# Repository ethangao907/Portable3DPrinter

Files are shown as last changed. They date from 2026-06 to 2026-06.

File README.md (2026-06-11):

# Portable 3D Printer
**I document everything here** https://www.instagram.com/gao.lab/

**Latest Reel** https://www.instagram.com/p/DYTzN6iu2yM/

**Engineering plastics capable, enclosed, direct drive, folding portable 3D printer that fits in a bag**

This printer collapses to a thin slab roughly the size of a laptop bag, then expands on a scissor-lift Z axis into a useful print volume. It is built almost entirely from 3D-printed parts on consumer machines, takes power from the same M18/DeWalt-class packs, and runs an enclosed heated chamber for ABS, ASA, and nylon. 
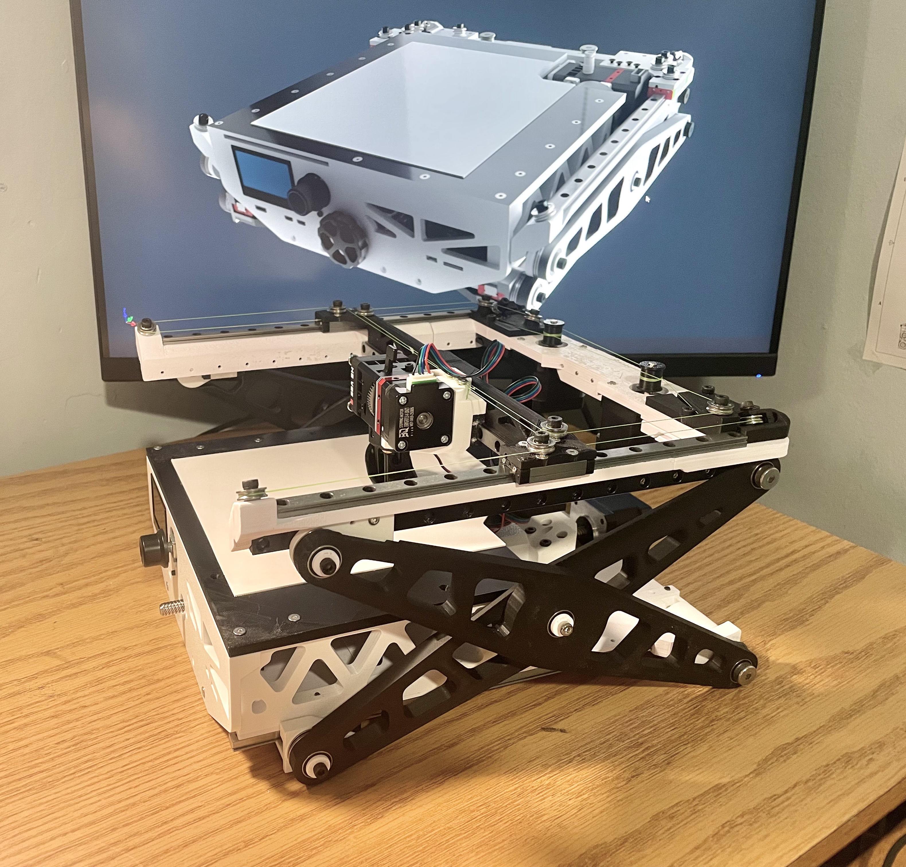
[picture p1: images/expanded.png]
Printer deployed


> **Status:** the v1 prototype is built and prints. v2, the version this repo is moving toward, is in active development. 

Desktop printers waste their whole volume when idle: the frame has to stay as tall as the full Z travel even when nothing is printing. This design stores that Z travel mechanically with a scissor lift, so the machine folds down to about **300 × 300 × 80 mm** and opens up to a **~180 × 200 × 175 mm** build volume. Nothing on the market targets *actual* portability, most "compact" printers are still stationary.

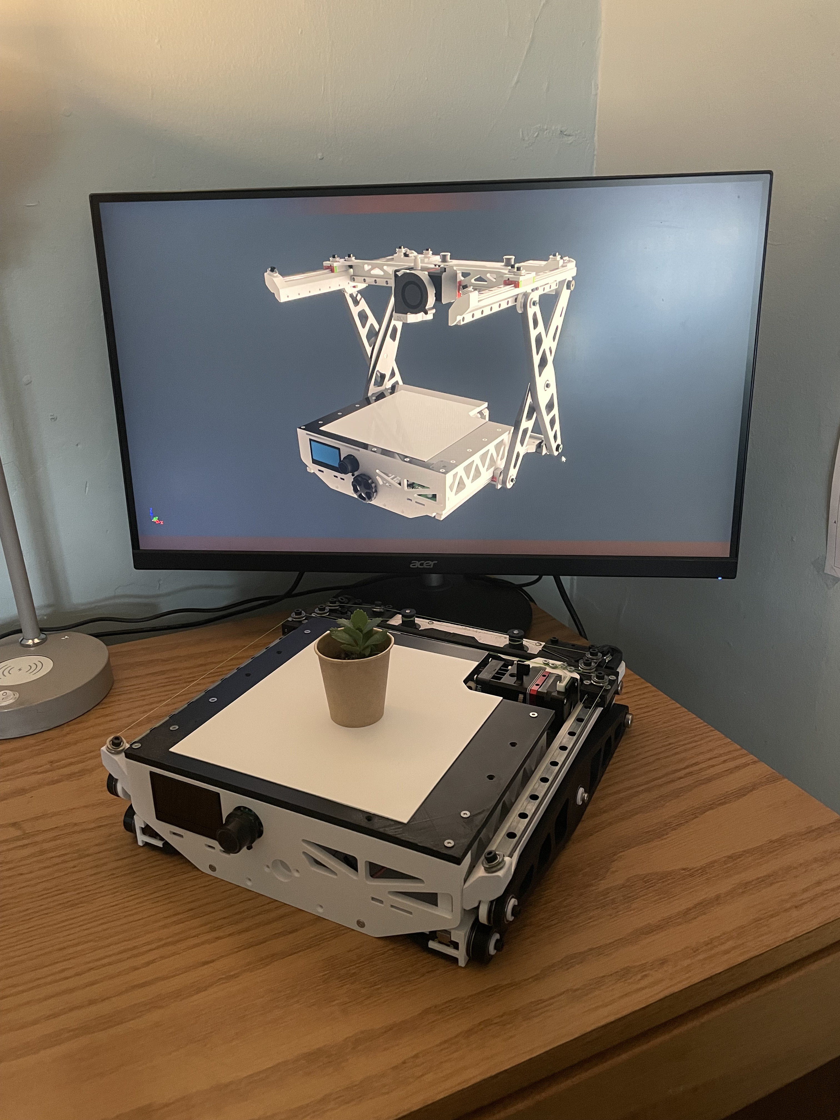
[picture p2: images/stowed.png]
Printer folded flat


The trade-off is that scissor lifts amplify backlash and load at low angles, so pivot quality, preload, bearing choice, and arm stiffness all matter. The build uses two preloaded pivots per side, thrust/axial bearings clamped with bolts, ~50 × 6 mm shoulder bolts at the stationary bottom pivot pair, and compliant printed clamps to hold everything tight.

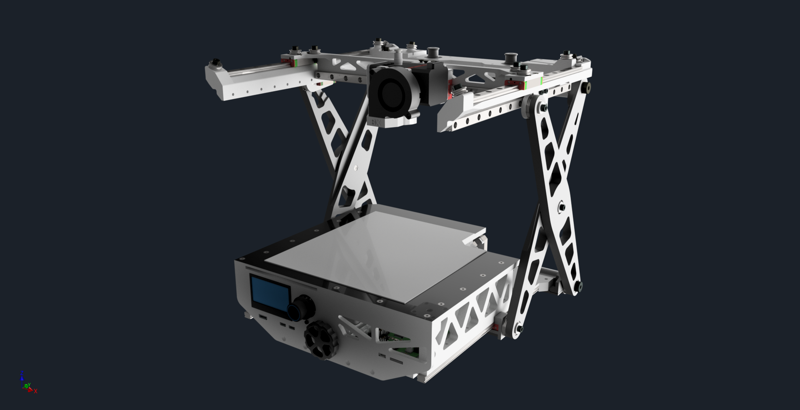
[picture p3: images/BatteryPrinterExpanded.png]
CAD Expanded

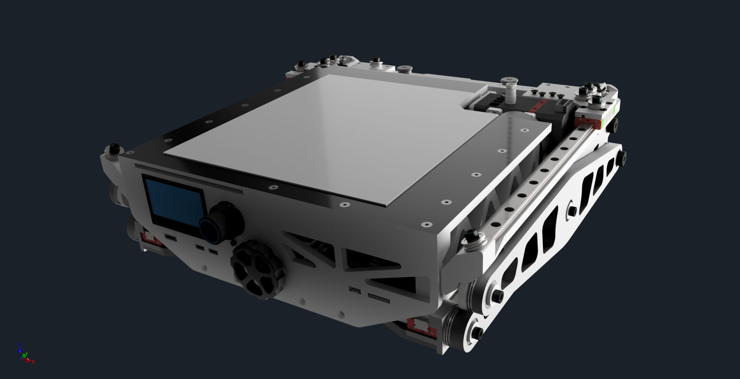
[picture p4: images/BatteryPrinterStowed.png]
CAD Stowed


## Inside the machine

The control stack runs a BTT SKR Mini E3 V3 with a Raspberry Pi 4 for higher-level control, on a 24 V bus, under Klipper. Klipper matters here specifically because a scissor lift has a **nonlinear** relationship between motor motion and nozzle height — software compensation maps motor position to true Z, which a conventional vertical gantry never needs.

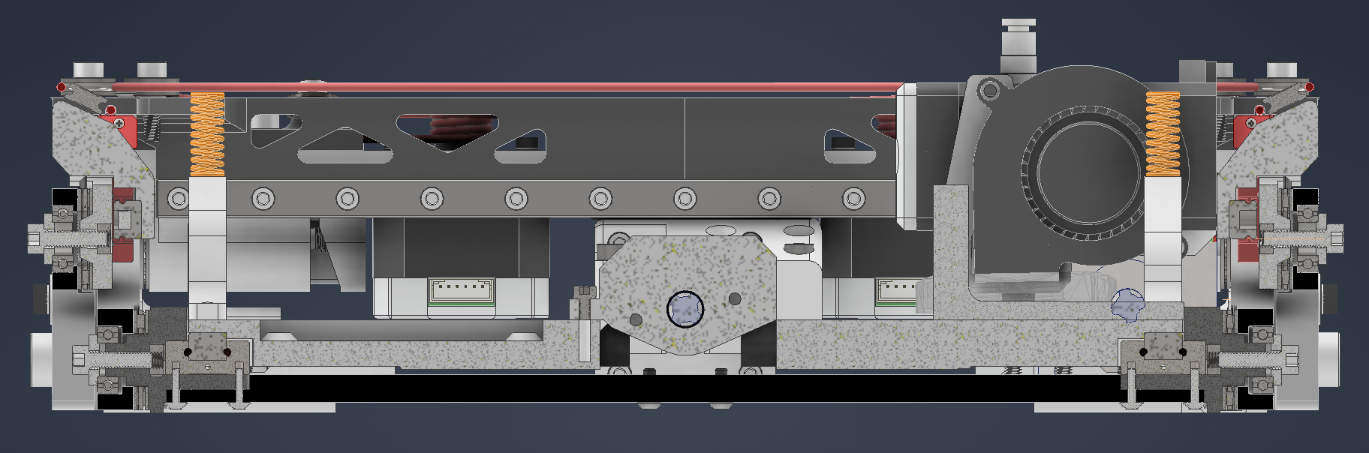
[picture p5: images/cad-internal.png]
Internal CAD


---

## Roadmap

v2 is a significant rework. The single central lead screw in v1 dictated the entire superstructure — the bottom bridge plate had to tie the two sides together, which forced the surrounding frames. **Removing the central screw in favor of two independent side lead screws collapses that dependency chain and opens a large central cavity** big enough to carry a full 1 kg spool inside the machine. Shortening the rear pivot bolts opens further space.

The other v2 changes follow from a deliberate repositioning. v1 was built around "battery + low power, *therefore* no heated bed." v2 drops the onboard battery entirely (it's a liability, and true off-grid printing is rare in practice), adds a **heated bed** and a **folding bellows enclosure** for a warm chamber, and takes power from a **power-tool battery** mounted on the front.

Remaining v2 work:

- Dual side lead screws with software Z-tilt leveling
- Folding bellows enclosure targeting a 50–60 °C chamber
- Heated bed sized for the chamber and power budget
- Power-tool battery mounting blocks (front), replacing the screen
- Custom 90° hotend with rear cable routing (kills the floppy top conduit)
- 3 mm GT2 belt drive — HBot first, falling back to CoreXY if racking forces are too high

## Bill of materials

*Coming soon.* Core components: MGN9 linear rails (×3), NEMA 17 motors, T8 lead screws, U-groove pulleys / GT2 belt, thrust + deep-groove bearings, shoulder bolts for pivots, BTT SKR Mini E3 V3, Raspberry Pi 4.

## Build instructions

*Coming soon.* The structure is designed to print on Ender 3–class machines with no machined parts. CAD and design files are in the [`Scissor 3D Printer`](Scissor%203D%20Printer) folder.

## Firmware

Klipper, with nonlinear Z mapping for the scissor geometry. Configuration and flashing notes will live in a `/firmware` folder.

## License

- **Firmware and software:** [GNU GPLv3](LICENSE) — modify and redistribute freely; derivatives must stay open and credit the original.
- **Hardware design files** (CAD, STEP, drawings): [CERN-OHL-S v2](LICENSE-hardware) — same share-alike philosophy, written for hardware.

- Build videos and project updates: [gao.lab](https://www.instagram.com/@gao.lab)

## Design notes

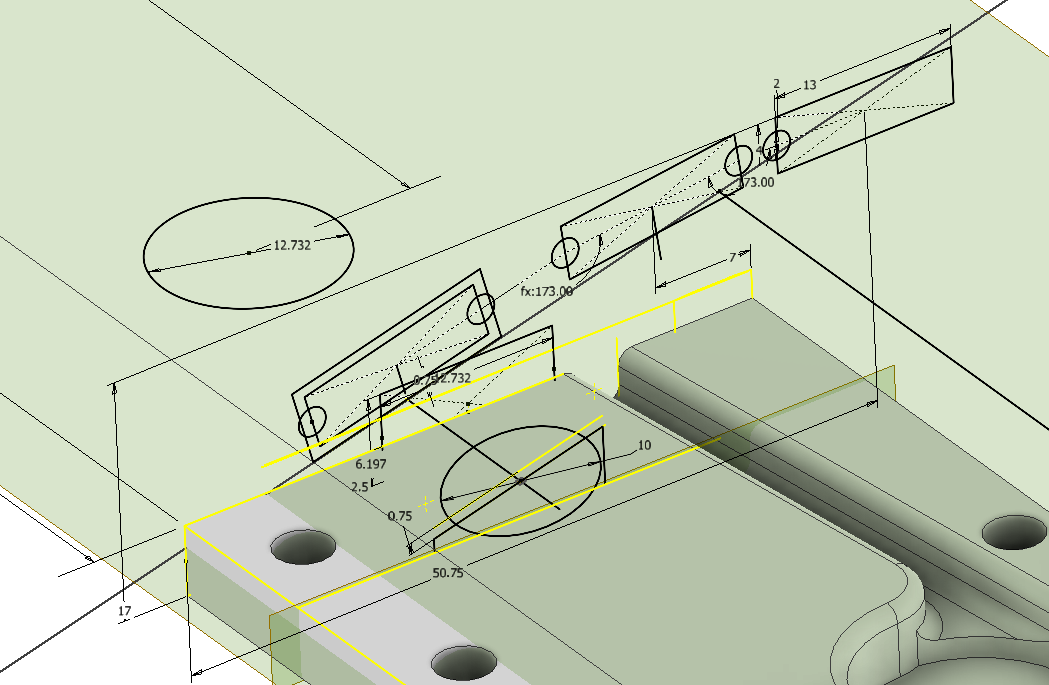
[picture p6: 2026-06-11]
images/Screenshot 2026-04-01 205350.png

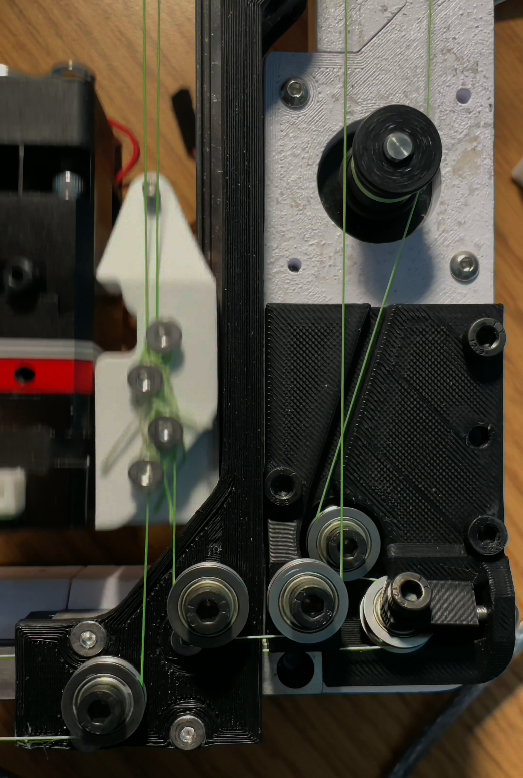
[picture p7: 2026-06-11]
images/Screenshot 2026-04-26 201614.png

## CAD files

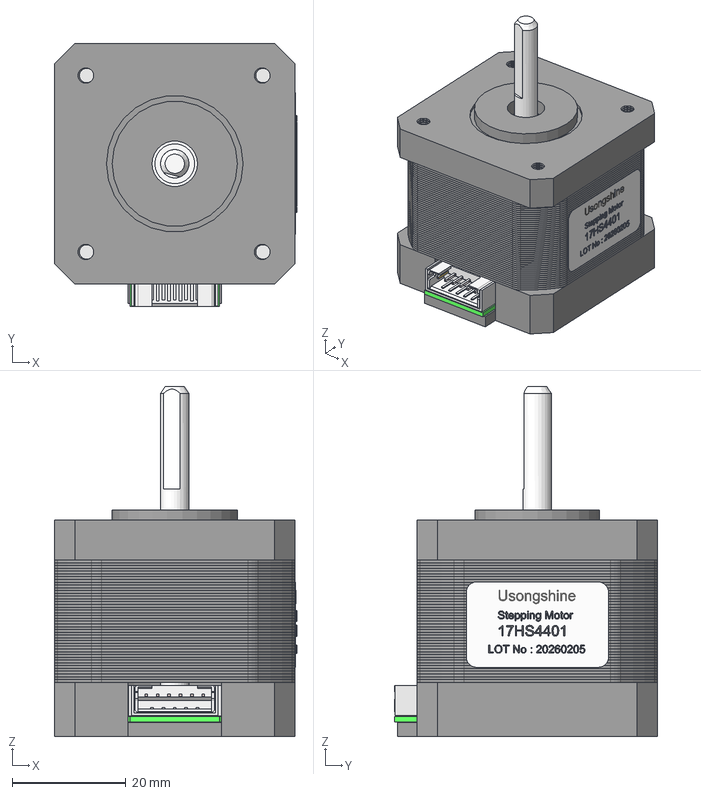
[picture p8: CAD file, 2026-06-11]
Scissor 3D Printer/nema17_17HS4401_b.step
42.5 x 46.2 x 61.5 mm
Bottom
Sheet_metal
Top_body
Axis
625ZZ_001 x 2
Sticker
C-440054-6
PCB
Conn_cover
M3x16-Vis x 4

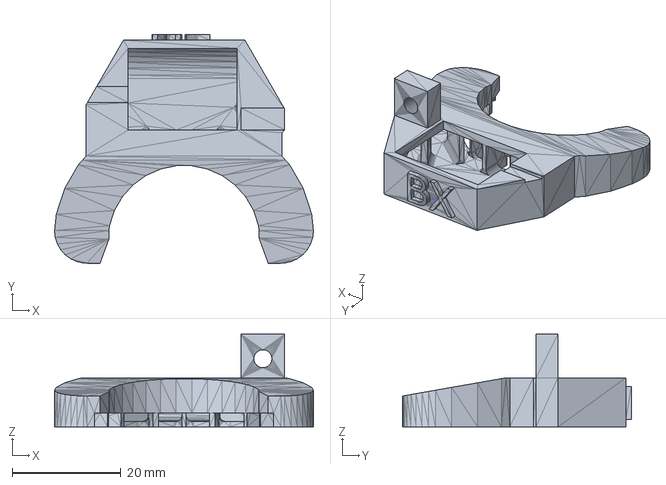
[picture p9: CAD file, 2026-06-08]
V2/ImageToStl.com_Fan_Duct/Fan_Duct.step
47.6 x 42.0 x 17.0 mm

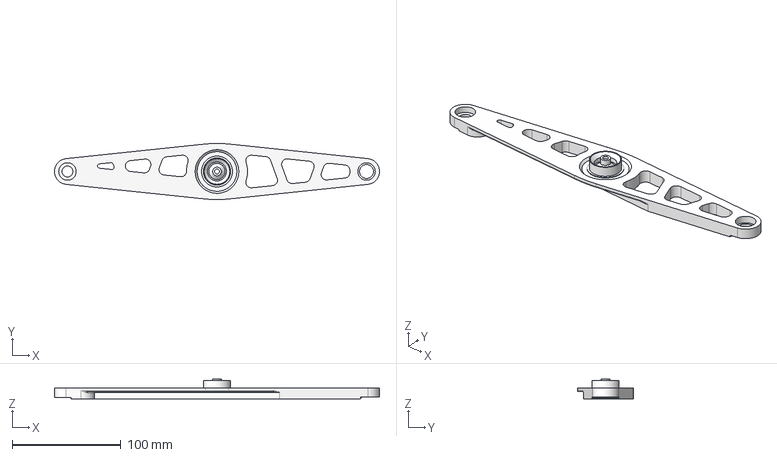
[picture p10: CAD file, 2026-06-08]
V2/Production/ScissorArmV2Inner.stp
298.8 x 51.6 x 18.0 mm

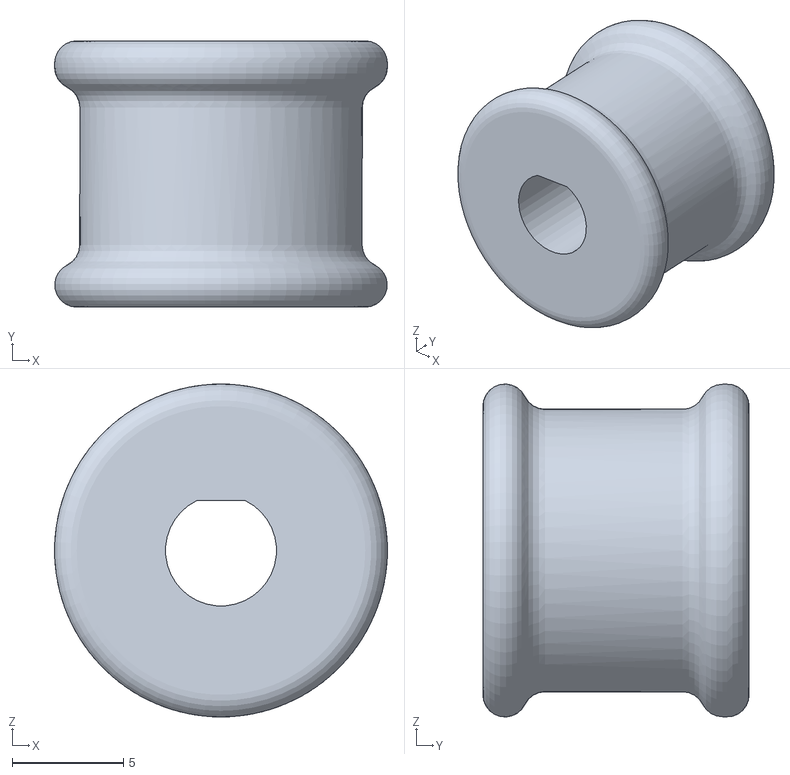
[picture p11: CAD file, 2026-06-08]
V2/STLs/Pulley.stl
15.0 x 12.0 x 15.0

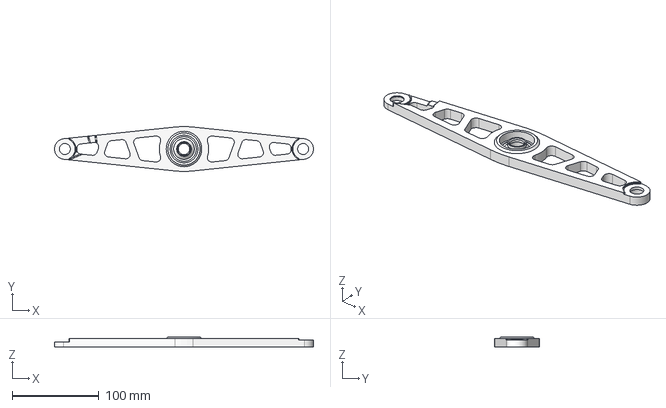
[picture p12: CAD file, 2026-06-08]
V2/Production/ScissorArmV2_MIR.stp
298.8 x 51.6 x 12.0 mm

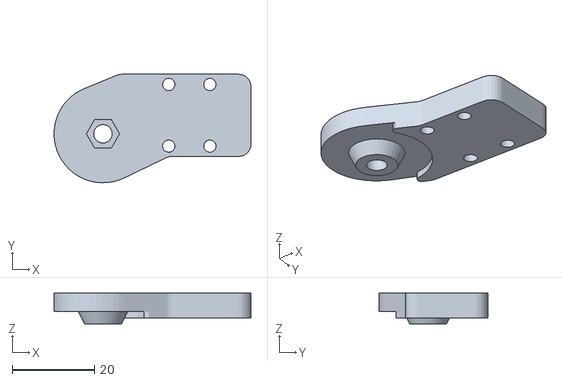
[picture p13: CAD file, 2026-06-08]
V2/STLs/UpperCarriagePivotMount_MIRV2.stl
47.9 x 26.4 x 7.50

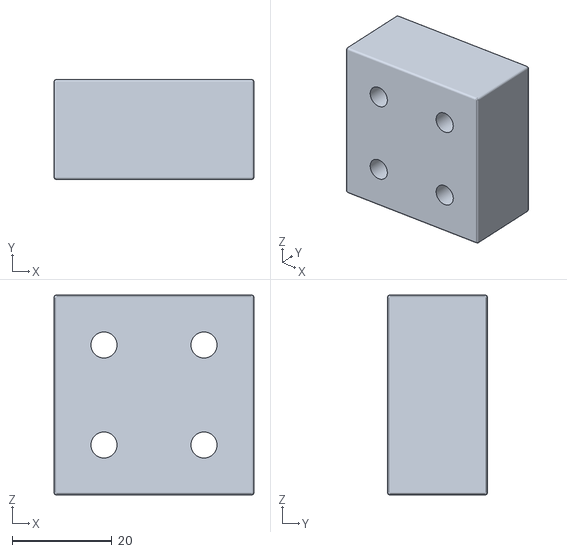
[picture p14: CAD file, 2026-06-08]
V2/4040_Spacer.stl
40.0 x 20.0 x 40.0

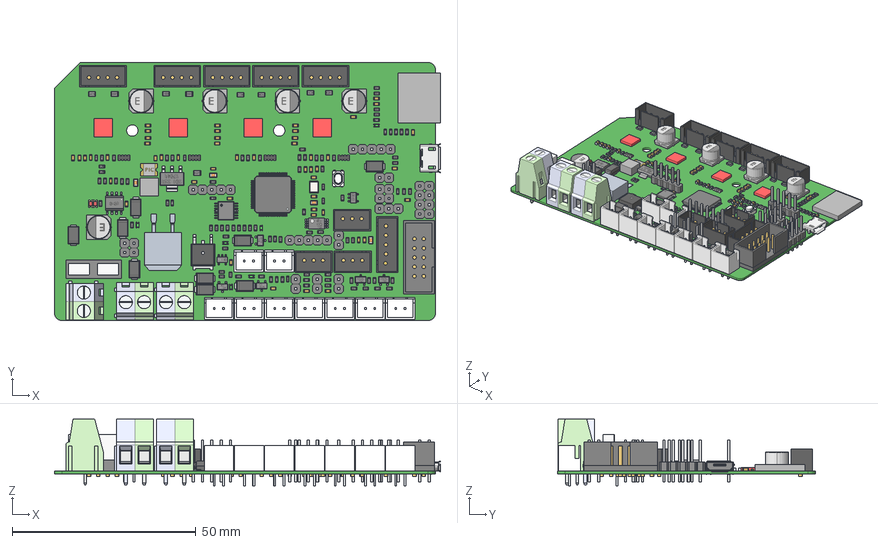
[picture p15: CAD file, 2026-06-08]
V2/BTT E3 SKR MINI V3.0.step
105.1 x 70.2 x 18.1 mm
Strip
Button
Sheet_Metal_Part6 x 2
Pin
DO214AC-SMA_S1G x 9
R0603 x 90
User_Library-XH2_54_2PIN x 9
User_Library-LED_0603_G_Pocket002 x 6
User_Library-LED_0603_G_Pad004 x 6
User_Library-LED_0603_G_Fillet x 6
User_Library-LED_0603_G_Pocket001 x 6
User_Library-LED_0603_G_Pad x 6
KF128 x 3
Extruded x 204
LOGO?
USB_micro_A
User_Library-led_0805 x 2
TQFP-64_10x10
TSSOP-8
SO-8
User_Library-0805_SMD_Capacitor x 4
SL-E x 5
R0805 x 9
TO-252
User_Library-R-0603-Array-4-1 x 4
SOT-223_MP04A
User_Library-GeyerElectronics_KX7
TO263
TSSOP14-1
SOT-23-5 x 2
User_Library-R1812-PTC

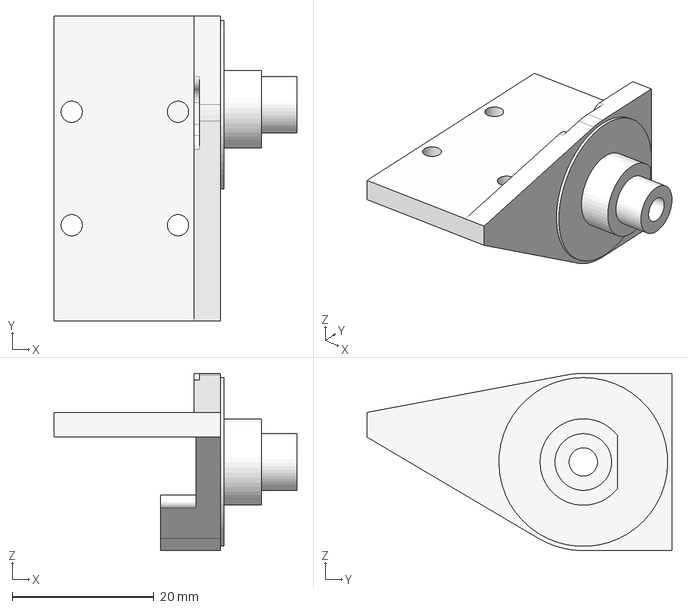
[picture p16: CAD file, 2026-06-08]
V2/Production/CarriagePivotMount.stp
34.3 x 43.0 x 25.0 mm

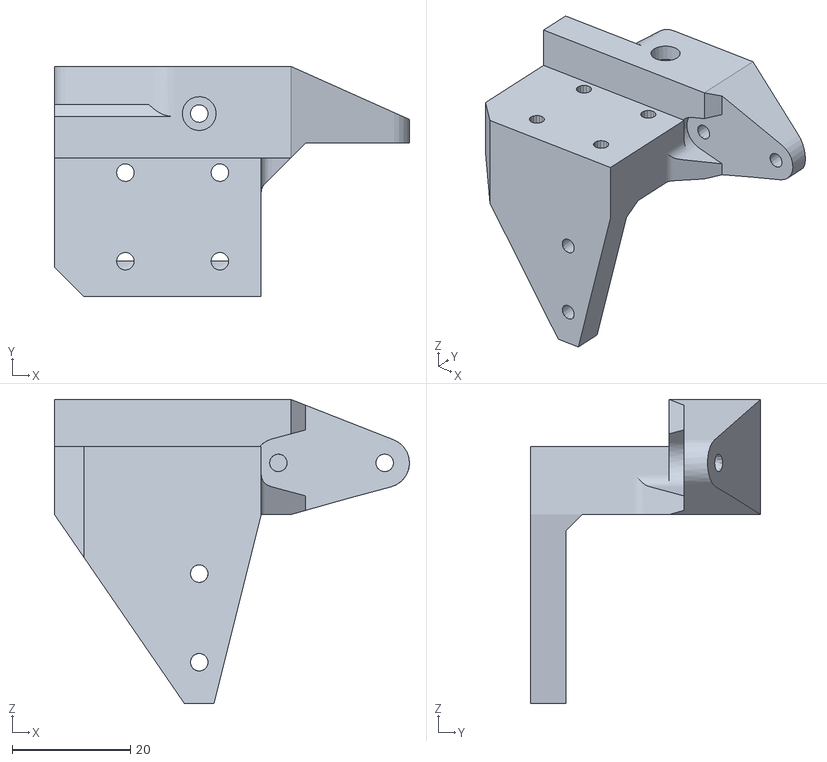
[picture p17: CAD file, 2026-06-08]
V2/STLs/ExtruderMount.stl
60.1 x 39.0 x 51.5

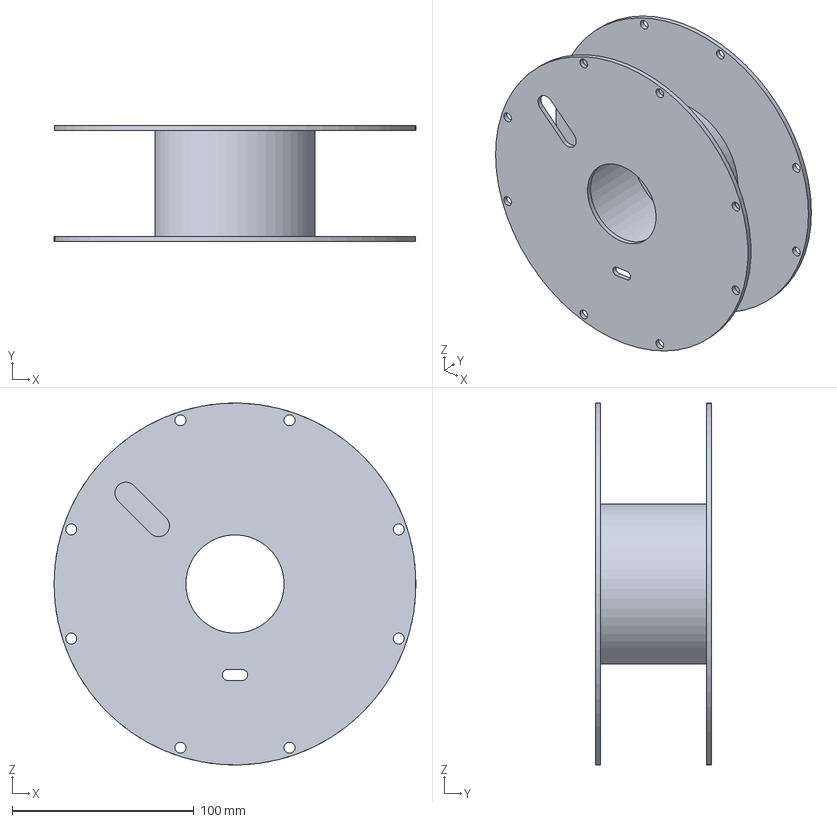
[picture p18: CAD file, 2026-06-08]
V2/cardboard spool v1.step
199.0 x 64.0 x 198.9 mm

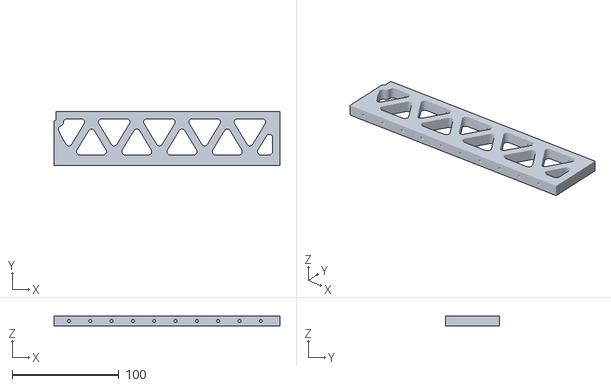
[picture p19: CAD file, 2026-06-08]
V2/STLs/LeftTruss.stl
212.0 x 51.0 x 9.00

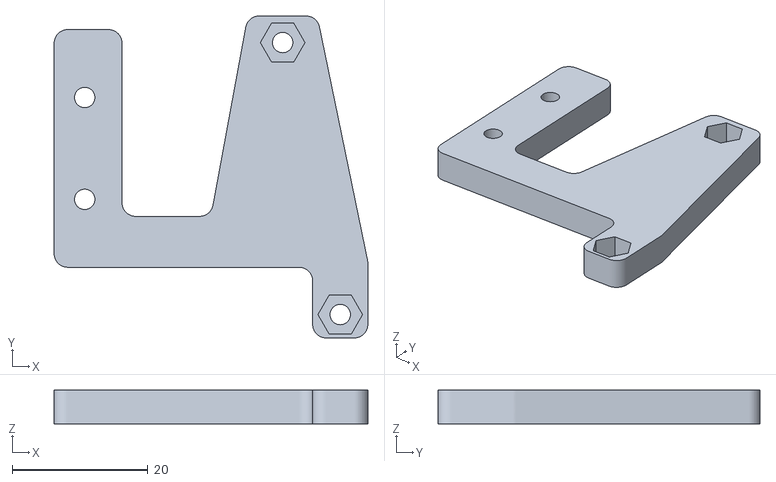
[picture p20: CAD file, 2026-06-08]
V2/STLs/FanMountV2.stl
46.2 x 47.4 x 5.00

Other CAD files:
V2/Main.dwg
V2/Production/ScissorArmV2.stp
V2/Production/CarriagePivotMount_MIR.stp
V2/Production/ScissorArmV2Inner_MIR.stp
Scissor 3D Printer/Nema17x38mm.ipt
Scissor 3D Printer/OldVersions/Main.0103.iam
Scissor 3D Printer/OldVersions/Nema17x38mm.0003.ipt
Scissor 3D Printer/nema17_17HS4401_b/nema17_17HS4401_b/nema17_17HS4401_b.ipt
V2/17HS16-2004D.STEP
V2/42SHD0034-20B.step
V2/42SHD0034-20B/42SHD0034-20B.ipt
V2/57155K621_Steel Flanged Ball Bearing.STEP
V2/57155K621_Steel Flanged Ball Bearing/57155K621_Steel Flanged Ball Bearing/57155K621_Steel Flanged Ball Bearing.ipt
V2/5909K31_Needle-Roller Thrust Bearing.STEP
V2/5909K44_0.032 Thick Washer for 1-2 Shaft Diameter Needle-Roller Thrust Bearing.STEP
V2/5972K241_Steel Ball Bearing.STEP
V2/6656K108_Steel Ball Bearing.STEP
V2/6656K108_Steel Ball Bearing/6656K108_Steel Ball Bearing/6656K108_Steel Ball Bearing.ipt
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

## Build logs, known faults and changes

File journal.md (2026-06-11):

# Portable 3D Printer — Project Journal
I compiled this with AI

Design log for the folding portable printer, January 2026 to present.

---

## Mid-January 2026 — Studying prior art

Pulled apart the chatlogs from Malte Schrader's xPrinter project (2019-2020), the closest existing scissor-lift folding printer.

What I extracted:

- Their nonlinear Z relationship and the Marlin firmware hacks they used (custom GenZ() function in planner.cpp, `zm = sqrt(246.02^2 - (62.5 + z)^2)`).
- Non-uniform ballscrew backlash made auto bed leveling impossible for them. Probing requires direction changes, the backlash changes with fold state, so software compensation could not work. Their proposed fix was a linear Z encoder, never implemented.
- Their housing flexed under the extreme forces of unfolding, the Z motor mount bent slightly, and pivot preload changed with extension.
- Bowden vs direct drive debate in their community. They chose Bowden purely for space. Decided on direct drive for my version. The scissor already adds enough variables (nonlinear motion, backlash, mechanical complexity) without stacking retraction tuning and tube friction on top.
- Diagonal arm mounting for weight distribution was proposed in their logs and never resolved.

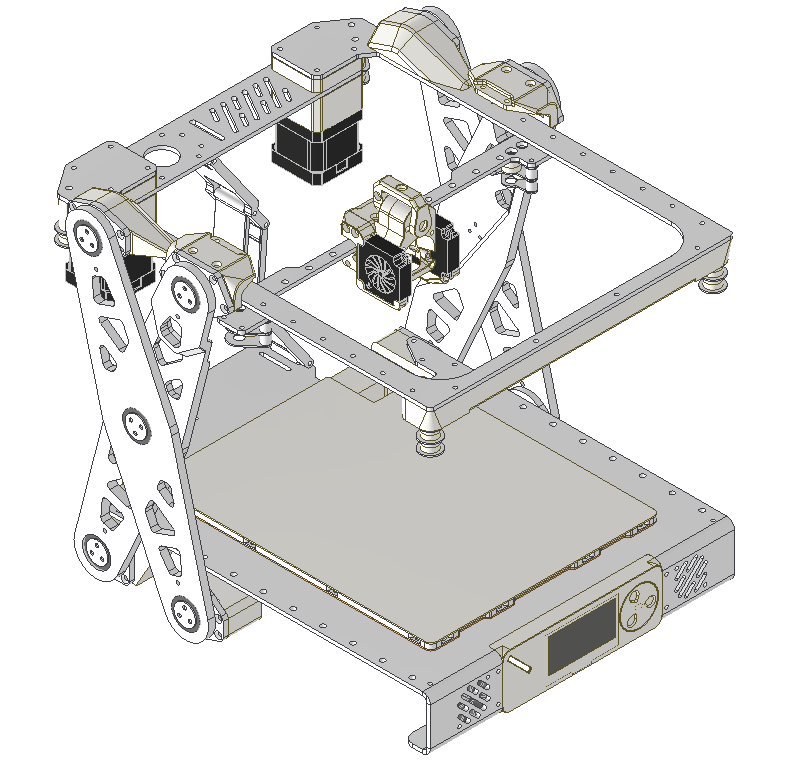
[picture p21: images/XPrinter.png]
XPrinterV1

*X Printer V1*

## Late January 2026 — Analysis phase

### Scissor kinematics

Derived from scratch. For link length L and base separation d:

- h = sqrt(L² − d²/4)
- dh/dd = −d/(4h) = −1/(2 tan θ)

Mapped mechanical advantage and lift force vs angle. Lift force for mass m is F = mg/(2 tan θ), so motor torque requirement drops as the scissor extends. Conclusions:

- Collapsing below θ ≈ 25-30° is useless (at 20°, 8.5mm of base travel per 1mm of height).
- Extending past 75-80° kills lateral stiffness (at 70°, lateral stiffness is ~40% of collapsed).
- Operating band set at roughly θ = 30-35° collapsed to 65-70° extended, sweet spot 40-60°.
- Link length sized as L = target height / sin(70°), landing around 200mm.
- Considered diagonal bracing wires or carbon rods from base corners to top platform for extended-state stiffness.

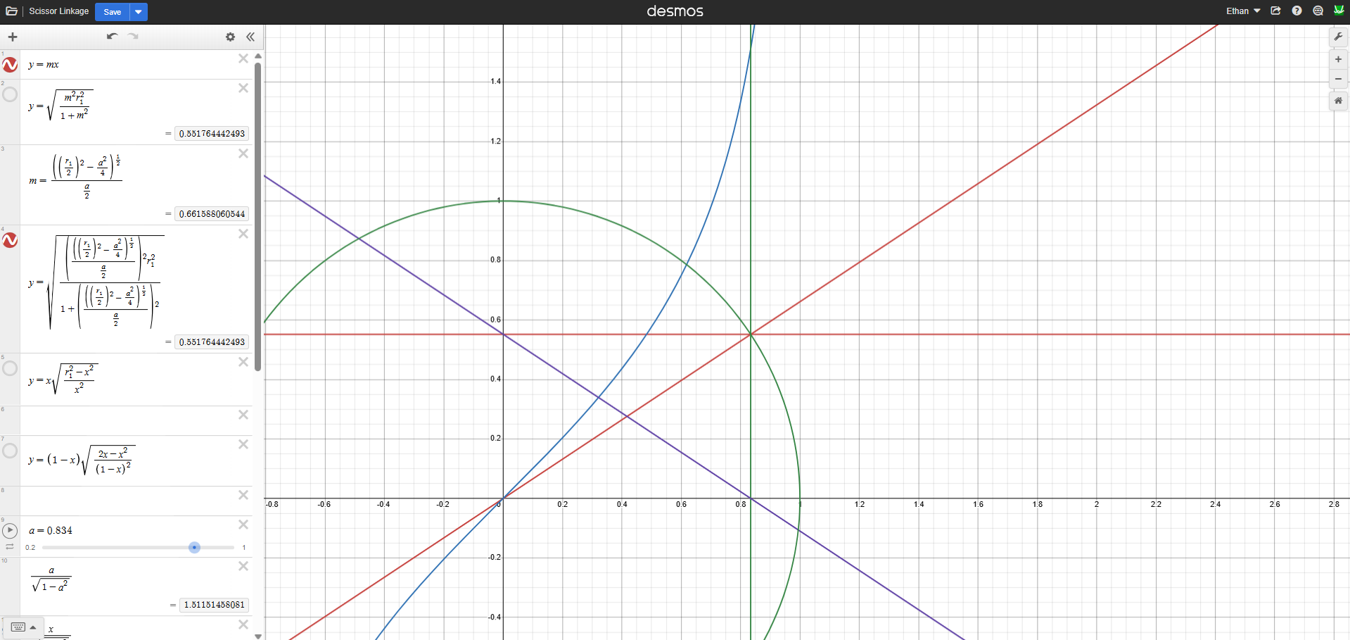
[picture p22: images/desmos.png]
Calculations in Desmos

*Calculations in Desmos*

### Minimum Z height

100mm is the absolute floor (covers ~80% of typical hobbyist prints), 150mm is comfortable (~95%), 75mm is too limiting (~50%). Aimed above 150mm.

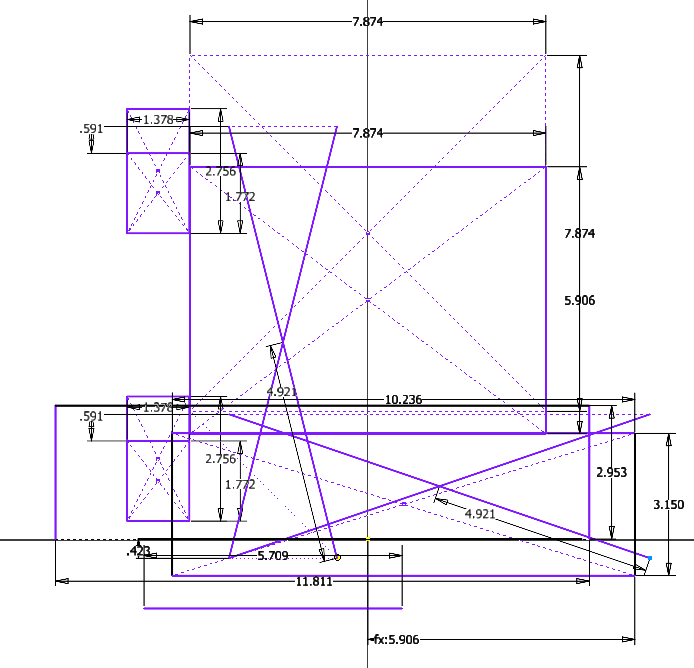
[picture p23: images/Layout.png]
LayoutSketch

*Layout Sketch for Z height*

### Z actuator trade study

Three options. Vertical central lead screw (simple kinematics, needs a screw as long as max height), horizontal base lead screw (compact, nonlinear, needs firmware compensation), belt at a corner (compact, geared small motor). Belts were argued hard for (zero backlash with tension, ~50g, 10x faster, quiet). Force math said it didn't matter for capability. NEMA 17 (0.4 Nm) on a 2mm lead gives ~1256N theoretical, ~628N at 50% trapezoidal efficiency, against a ~13N load (bed + mechanism + part), a 48x safety factor. 8mm lead still gives 12x and is 4x faster, so if screws, 8mm lead and no planetary gearbox. The gearbox added 200g, $35, and backlash to solve a problem that didn't exist.

### Extruder trade study

Compared Sprite (280g, heaviest), BIQU H2 (220g, 7:1, 80-90N extrusion force, integrated hotend), Sherpa Mini (90g, recommended for the power and weight budget), Orbiter V2 (140g), LGX Lite (160g), DIY Bowden (lightest, worst quality). Chose the H2 for v1 despite the weight.

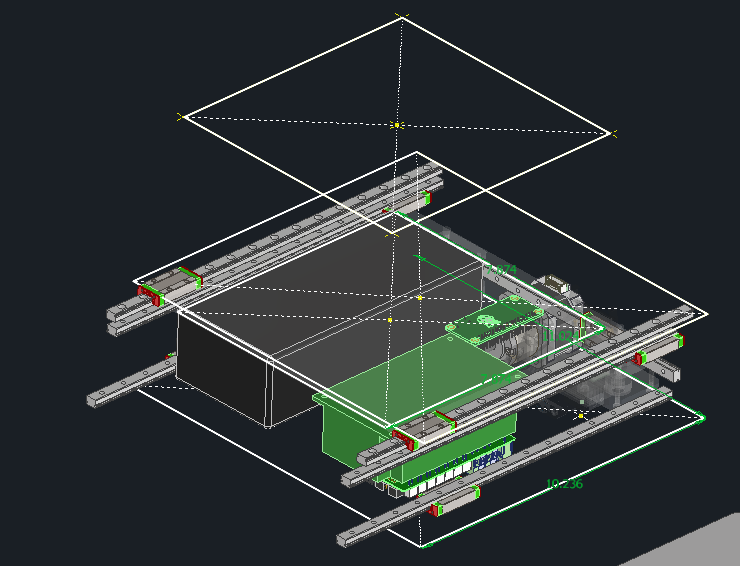
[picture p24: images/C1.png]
Cad Inception

*Cad Inception; All concrete hardware imported*

### Power architecture

Two architectures considered. Off-the-shelf DC UPS module (turnkey, protections built in, sub-10ms switchover) vs custom ideal-diode OR-ing (LTC4352/LTC4353 controller or TPS2121 power mux, 6S BMS with 4.2V/cell overcharge and 3.0V/cell overdischarge cutoffs, balance, 15-20A overcurrent). Went custom.

Worked through LiPo fundamentals to ground the design. Voltage maps directly to state of charge (4.20V full, 3.30V effectively empty, below 3.0V copper dissolution permanently damages the cell, above 4.2V dendrite formation risk). Capacity 22Ah at 22.2V nominal is ~488Wh. Key realization on charging, the Meanwell PSU set to exactly 25.2V with its 13A current limit performs CC/CV natively. The current limit is the CC phase, the regulated output is the CV phase, current tapers naturally as battery voltage approaches the rail. No additional charge circuitry needed, the BMS handles protection and the ideal diode handles the path. End behavior is laptop-like, plug or unplug mid-print in either direction with no interruption.

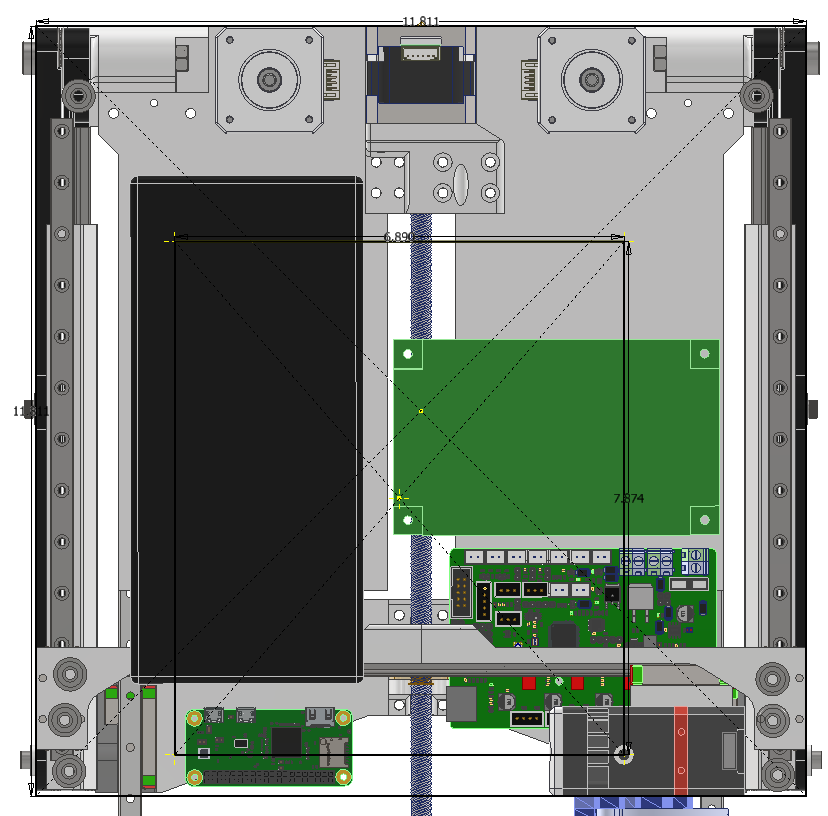
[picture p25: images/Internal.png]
Internals

*Internal electronics layout (note huge battery)*

### XY mechanism alternatives

Reviewed the CoreH-bot paper (planar single-belt mechanism, 14 pulleys, 4 motors, same Jacobian as CoreXY, balanced torques like CoreXY without 3D belt routing, 250mm/s at ~0.1mm tolerance in their prototype). Considered for compactness and power efficiency. Stayed with CoreXY.

### CAD methodology

Layout sketches and spatial budgets before any geometry. Hardware defines positions, designed parts fill the gaps. Clearance tables (3mm rotating parts, 2mm belts, 10-20mm around the hotend, 10mm wiring, fastener access for hex keys, 2-5mm PCB to frame, 10-20mm battery ventilation). Interference detection run at every extreme position after every added part. Motion studies of the scissor across full Z to catch short cables and collisions before building. Phase order, hardware placement, frame, motion system, toolhead, electronics, cosmetics. Each part made as big as possible without colliding with others. When a new part wouldn't fit, space would be carved out of existing parts to make room, requiring considerable strength analysis.

Misc from this period, 90° bend duct losses on the blower fan, battery bay ventilation requirements.

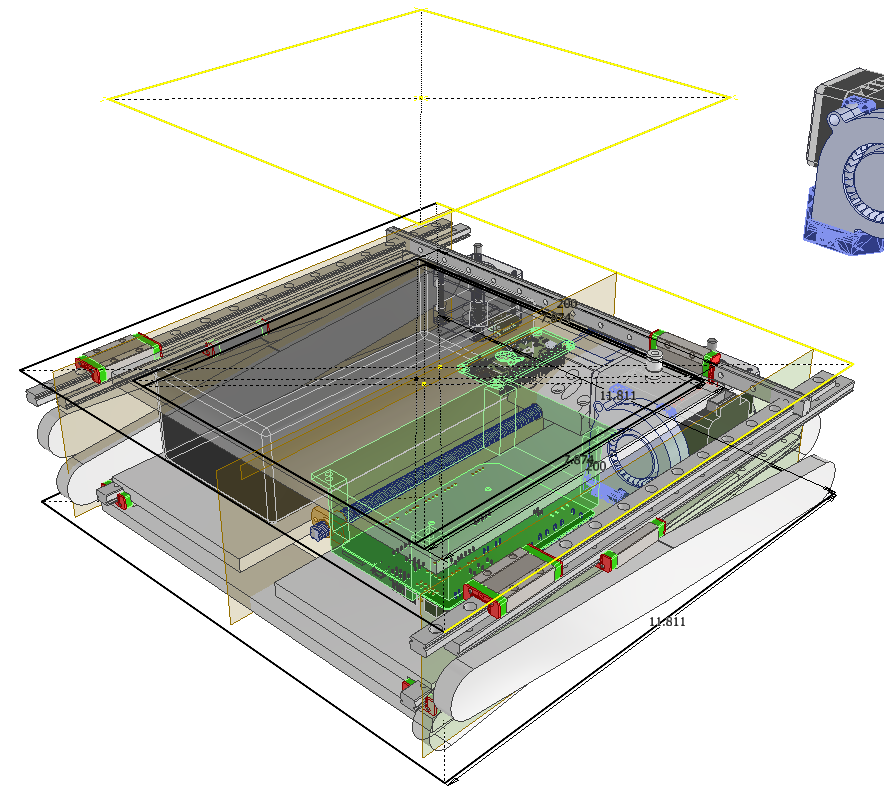
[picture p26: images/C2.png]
Cad Progress 2

*Cad Progress 2*

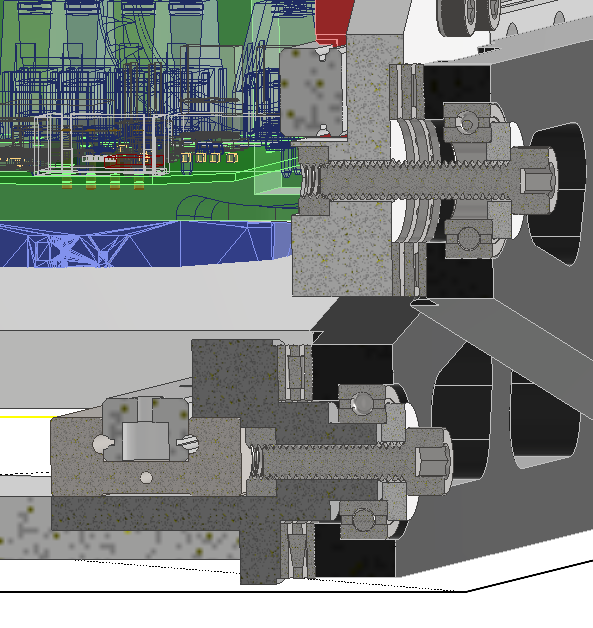
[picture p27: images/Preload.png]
Preload_Stacks

*Preloaded joints for increased scissor rigidity*

---

## February–March 2026 — V1 CAD and fabrication

Most CAD happened here, less documented research and calculations. Notably, I fit 3 linear rails, two axial + thrust bearing preload stacks, and a CoreXY cable routing into a 25x80mm cross section. Parts reached up to V7.

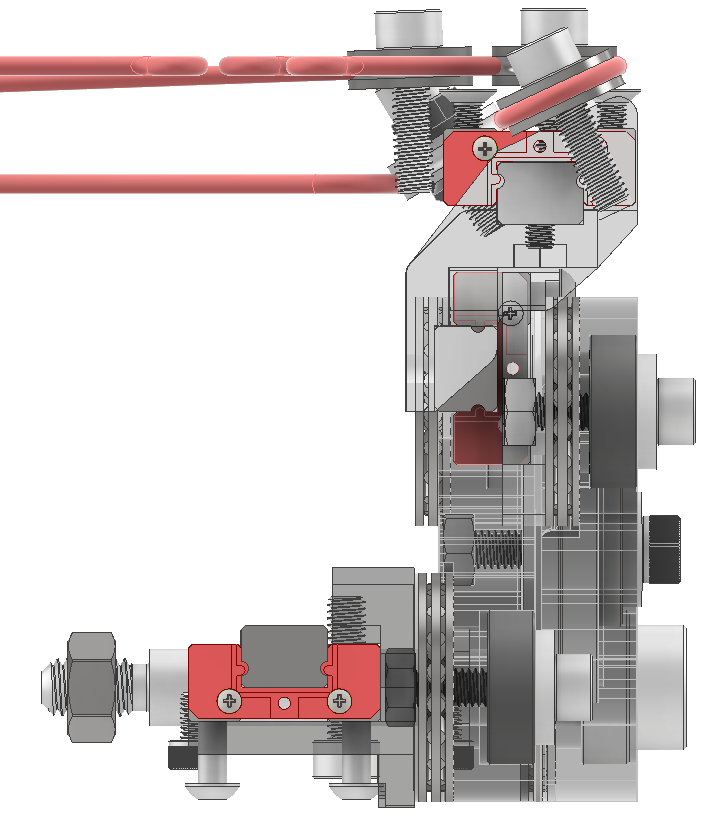
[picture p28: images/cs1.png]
Cross section

*This packing is my magnum opus*

The packaging process that emerged, set the baseline envelope first (300×300×80mm fold, scissor lift, 10h battery target, direct drive toolhead), calculate from constraints to a real parts list, import parts into CAD and arrange until a configuration fits, then design the printed "glue" brackets that hold the off-the-shelf parts in that arrangement.

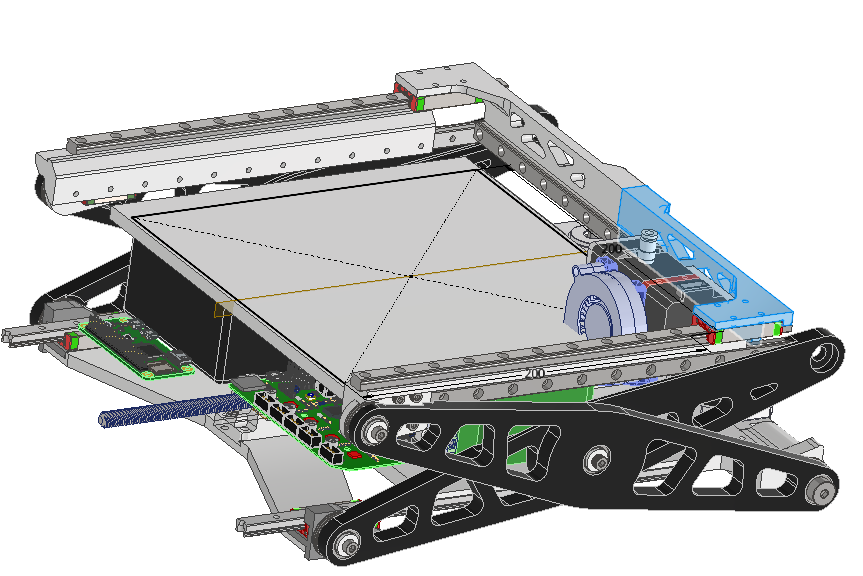
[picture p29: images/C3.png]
Cad Progress 3

*Cad Progress 3*

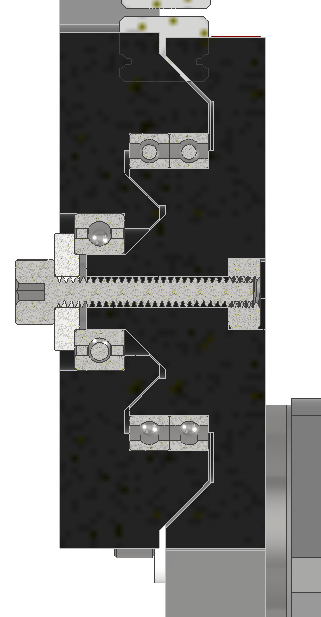
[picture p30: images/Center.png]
Central Preload

*Center pivot preload stack*

### March 30 — Dyneema pulley design

- Grooved vs smooth idlers. Grooved wins for round slippery cable. U-groove with radius 5-10% larger than cable radius, V-grooves wedge and wear.
- A true helical groove on a cylinder keeps constant effective radius, the ramp/cam concern only matters at crossover regions and is negligible at small pitch.
- For idlers with axially offset entry/exit, tilting the pulley a degree or two (arctan(Δz/2L)) keeps the cable in a single circumferential groove. No helix needed.
- For the multi-wrap drive capstan, a smooth drum was chosen over a helical groove. The helix forms naturally from approach angle, constant radius everywhere, at the cost of possible axial walking.
- Wrap count sized with the capstan equation using a conservative Dyneema-on-PLA COF of 0.05-0.10 against a worst-case inertial load of F = ma ≈ 0.25kg × 3 m/s² = 0.75N at a modest 3000 mm/s² CoreXY acceleration.

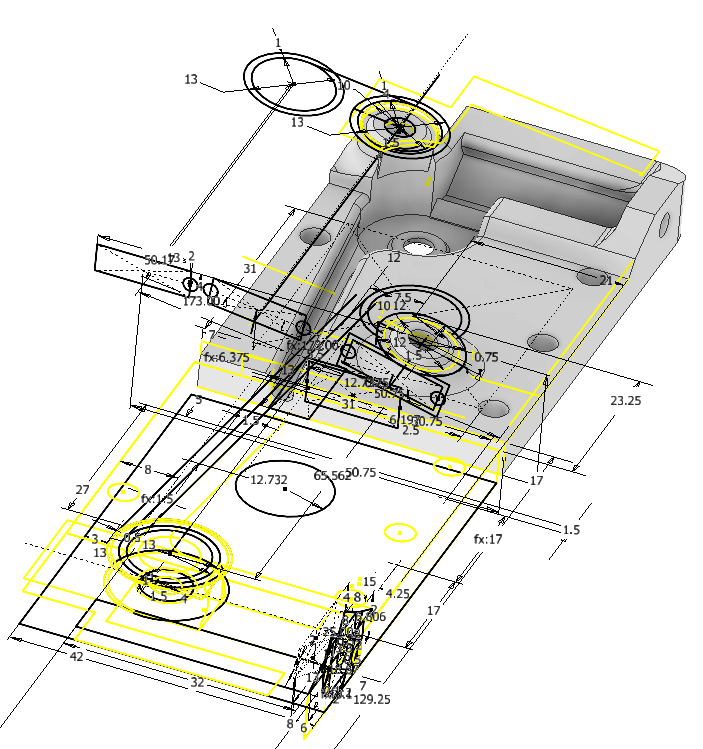
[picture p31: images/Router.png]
Single part to route the cable was very complex

*Single very complex part to route the cable optimally*

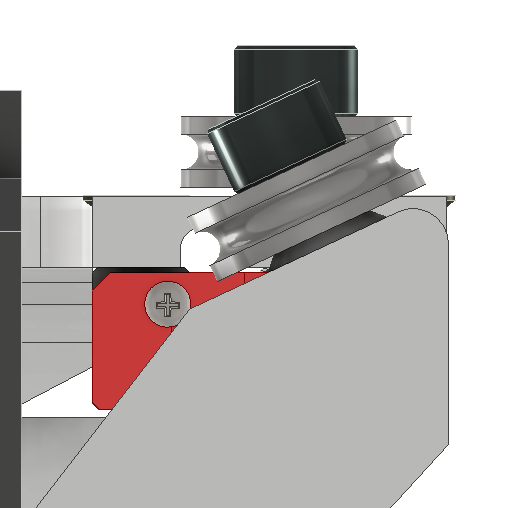
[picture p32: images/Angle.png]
Angled idlers passing string under the gantry plate

*Angled idlers passing string under the gantry plate to save space*

### April 2 — Drive pulley sizing and routing

- Drum diameter set to 80/π mm so circumference is exactly 80mm and steps/mm divides cleanly. Klipper doesn't strictly need integer steps/mm, but it avoids rounding accumulation and makes calibration math clean.
- Effective wrap diameter includes one cable diameter on top of the groove minor diameter, and changes slightly under tension.
- Checked whether a wrap-angle difference between the two CoreXY paths matters (3 wraps vs 3 wraps + 10° at 10N). Capstan ratio difference ~1%, slip impossible at that wrap count. The real path-matching concern is stretch consistency between unequal path lengths, not wrap angle.
- Routing geometry decision, linear height increase across a 2-segment span requires one bearing tilted in both x and y.

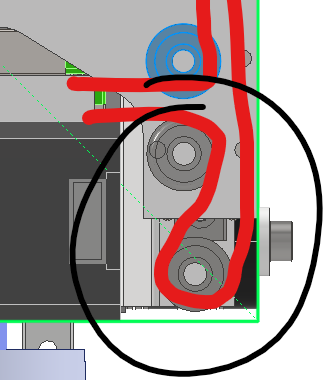
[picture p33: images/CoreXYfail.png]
Realizing that pulleys with relative motion in CoreXY must be collinear

*Realizing that pulleys with relative motioin in CoreXY must be collinear or else conservation of string is violated*

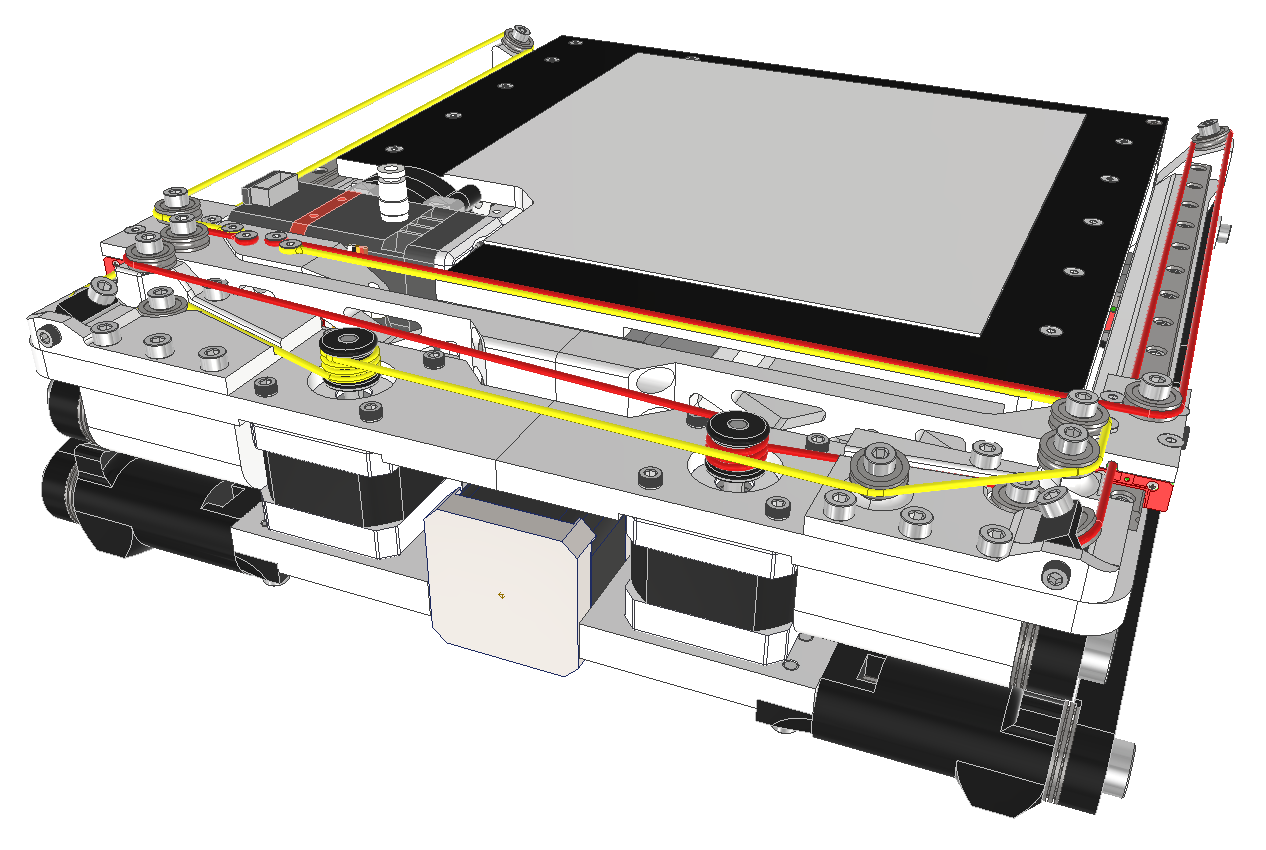
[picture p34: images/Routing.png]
Completed Routing

*Completed cable routing path*

### April 4 — Nonlinear Z in Klipper, v1 spec complete

Four approaches evaluated for the scissor's nonlinear motor-to-nozzle mapping:

1. Custom kinematics module in `klippy/kinematics/` (the correct answer). Base on corexy.py, override only the Z portion with forward/inverse scissor kinematics.
2. Lookup table via gcode_macro. Jinja2 has no asin, would need polynomial approximation or discrete interpolation. Fragile.
3. z_thermal_adjust abuse. Wrong tool, it's an additive thermal correction.
4. Dynamic step_distance scaling. Breaks homing.

Key derivations needed, exact screw-travel-to-θ relationship, where Z=0 sits on the curve (stay away from the collapsed singularity), and the θ range that keeps step resolution usable.

v1 spec as fully written at this point:

- 180×200×175mm build volume in a 300×300×80mm folded envelope, ~85% volumetric efficiency.
- Nested scissor arms, every pivot preloaded with a thrust + axial (deep groove) bearing combination clamped by bolt and nut. The stationary bottom pivot pair, the most critical joints, use 50mm × 6mm shoulder bolts in compliant printed clamps.
- One MGN9 rail nests into the scissor arm itself, so three MGN9 rails, two preloaded pivot assemblies, and the full CoreXY cable routing coexist in an 80×25mm cross section.
- CoreXY driven by Dyneema instead of GT2. The cable crosses itself multiple times, threads under mounting plates, tensioned by two adjustable rear screw tensioners. Dyneema twists out of plane between pulleys, which belts cannot, and is 20-40x stiffer per cross section, worst-case position error ~0.08mm over full travel.

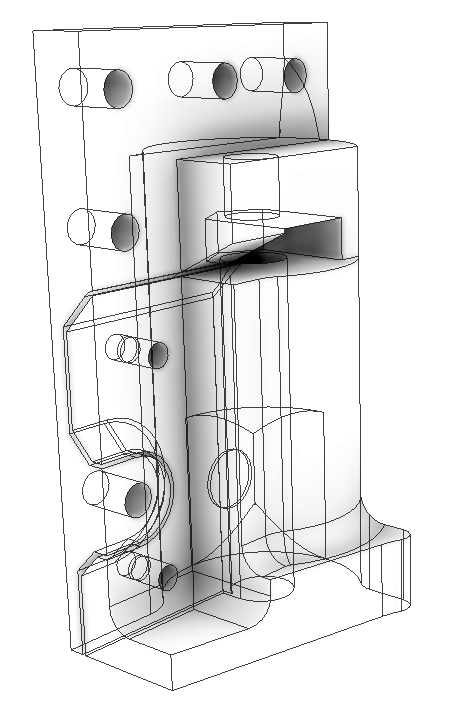
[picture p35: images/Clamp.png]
Shoulder bolt clamping part and thrust bearing mounting part

*Shoulder bolt clamping part and thrust bearing mount; took me a whole week to get right*

Cross section showing all scissor assemblies
*Cross section showign all scissor assemblies*

- BIQU H2 direct drive, 4020 blower for part cooling, BLTouch at 0mm X / 24mm Y offset to minimize lost bed mesh area.
- 6S 22Ah LiPo + slim 400W Meanwell 24V PSU through the ideal-diode OR-ing circuit. Simultaneous wall printing and charging, seamless switchover both directions. ~50W system draw with no heated bed, 8-10 hour theoretical runtime.
- Klipper on a Raspberry Pi Zero 2W over WiFi (later Pi 4 in the built machine), BTT SKR Mini E3 V3, BTT Mini 12864 display.
- Every printed component fits a 220×220mm bed, no machined parts.

Also worked out a battery level display hack, expose the pack voltage through a fake `[temperature_sensor]` via `[adc_temperature]` scaling so Mainsail shows it in the top bar, or a custom KlipperScreen panel.

### April 20 — Capstan walking

The major v1 failure mode. Under rotation the Dyneema migrates axially along the smooth drum and bunches at one end until the system jams. Rope clumped, wraps locked, the carriage stalled. The lesson, cable behavior on small drums with mismatched inlet/outlet heights is a contact mechanics problem, not a geometry problem.

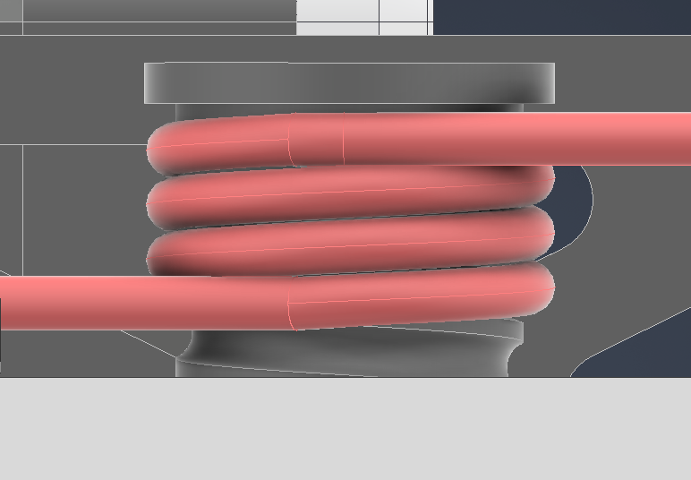
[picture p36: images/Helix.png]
Pulley string engagement angle

*Pulley string engagement angle causes thicker string to walk*

Solutions considered, helical grooves (ruled out, unlimited bidirectional rotation and no axial room), fleet angle correction via shaft tilt, fairlead pulleys, Jake Read's double idler, translating drum. Converged on a self-tailing winch mechanism from sailing hardware as the most promising structural fix. The self-tailing guide physically forces the rope back to a fixed axial exit position every revolution, eliminating the walk instead of slowing it.

Quantitative pass:

- 80/π mm drum, worst-case diagonal move sqrt(200² + 175²) ≈ 266mm = 3.3 drum rotations.
- Effective rope modulus E ≈ 40 GPa for braided Dyneema (raw UHMWPE fiber is 100-130 GPa, discounted for braid angle, bedding-in, and ~65% packing).
- Per-diameter results over the 1030mm path with anchor distances of 65mm (input side) and 140mm (output side):

| Diameter | D/d | Walk per full move | Fleet-angle violation | Stiffness | Tension bump |
|---|---|---|---|---|---|
| 2.0mm | 12.7 (6.4 on small idlers) | 6.6mm | 0.52mm | ~88 N/mm | 46 N |
| 0.8mm | 31.8 | 2.64mm | 0.08mm | 13.6 N/mm | 1.1 N |
| 0.5mm | 51 | 1.65mm | 0.031mm | 5.0 N/mm | 0.16 N |
| 0.3mm | 85 | 0.99mm | 0.011mm | 1.8 N/mm | 0.02 N |

- 2mm is badly oversized on every axis. 0.5mm is the sweet spot, breaking strength 350-500N against 20-30N peak loads, 15-25x safety factor. 0.3mm works but knots and splices (30-50% strength loss) start to matter at 5-12x.
- Sourcing, high-quality 8-carrier braided fishing line (Sufix 832, PowerPro Super 8 Slick) is functionally identical to marketed Dyneema rope at a fraction of the cost, 80-100 lb test corresponds to the target diameter.
- Perspective on tension error sources, acceleration loads (~2N at 5000 mm/s² with a 400g head), creep bed-in (10-20% preload loss over the first days, slow creep after), enclosure temperature, and capstan friction at each direction change are all 10-100x larger than fleet-angle effects. Fleet-angle stretch and the positioning violation are the same 0.08mm viewed two ways, not additive.

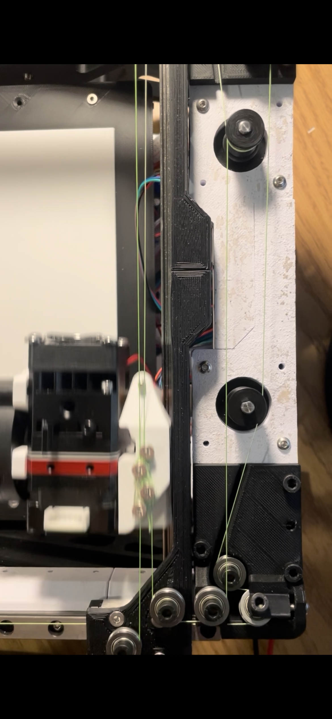
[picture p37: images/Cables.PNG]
Solution: thinner string (fishing line)

*Solution: thinner string (dyneema fishing line)*

---

## May 2026

### May 8 — Electronics bring-up, nonlinear Z round two

Motor spin tests. Second pass on the kinematics with new physics caught:

- Resolution at the high-gain end. Near collapse, dz per microstep = 2L·cos(θ)·(2π/steps_per_rev)/gear_ratio. For 2L = 200mm, 1600 steps/rev, no gearing, ~0.78mm per microstep at the bottom, 4x a typical layer height. Either gear down ~30:1 or keep the printable range above θ = 30°, where the gain variation across the range is a manageable ~5x (cos30/cos80).
- Velocity limits. Motor velocity = toolhead velocity / gain, so the motor flies at the low-gain top of travel. max_z_velocity is set by worst case, homing and probing speeds need attention.
- Implementation path confirmed, custom kinematics file with delta.py as the reference (delta Z is also nonlinear with tower position), a C helper through `setup_itersolve` in `klippy/chelper/`. The win over gcode remapping or post-processing, bed_mesh, probing, and axis_twist_compensation all operate in nozzle Z space and keep working.

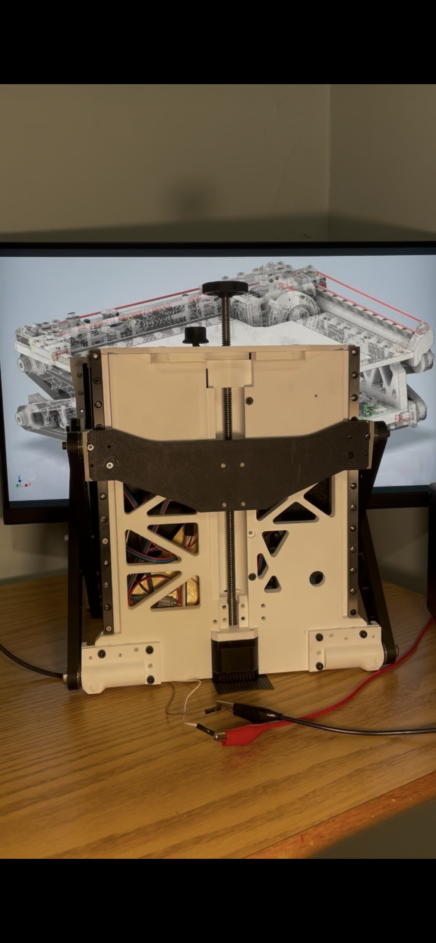
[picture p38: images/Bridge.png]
Nonlinear Z bridge assembly

*Nonlinear-Z bridge assembly*

### May 9-15 — V1 status, captured mid-build

Status at this point, mechanical architecture fully designed, CAD complete, several structural parts printed, upper gantry partially assembled. The scissor pivot system was the most-iterated section, getting scissor stiffness right without machined components took multiple revisions. The active technical problem was XY cable routing at the spool level, with thinner cable (~0.8mm), level-wind guidance, and GT2 on selected paths under evaluation.

Competitive landscape as mapped, Positron V3 is the nearest prior art but runs a 200W external PSU. Prior battery attempts (a 2020 student DVD-drive build, TOME, Pbag) failed on ~3 hour runtimes, tiny volumes, or never reaching reproducible form. Reference desktop machines (A1, MK4, Ender 3) pack ~220×220×250 build volumes into footprints roughly 4x the print area, mostly frame, motors, and dead air. Positron hits ~95% volumetric efficiency but is mains-tethered.

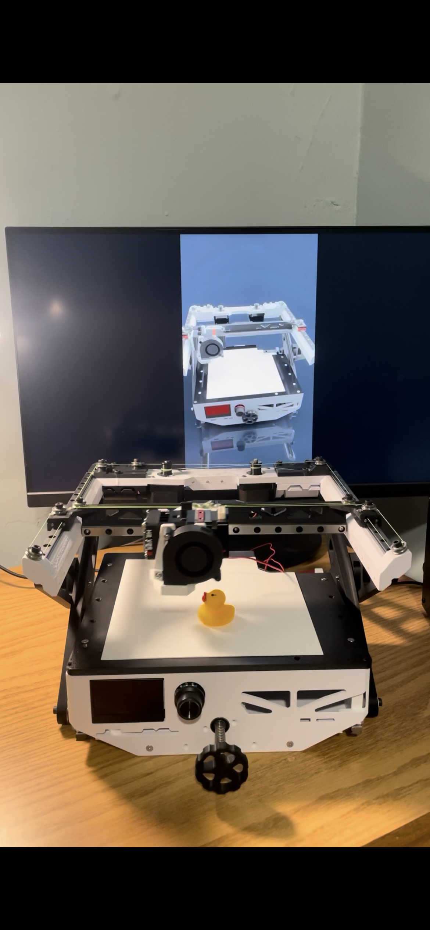
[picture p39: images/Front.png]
Front view V1

*V1 Front view*

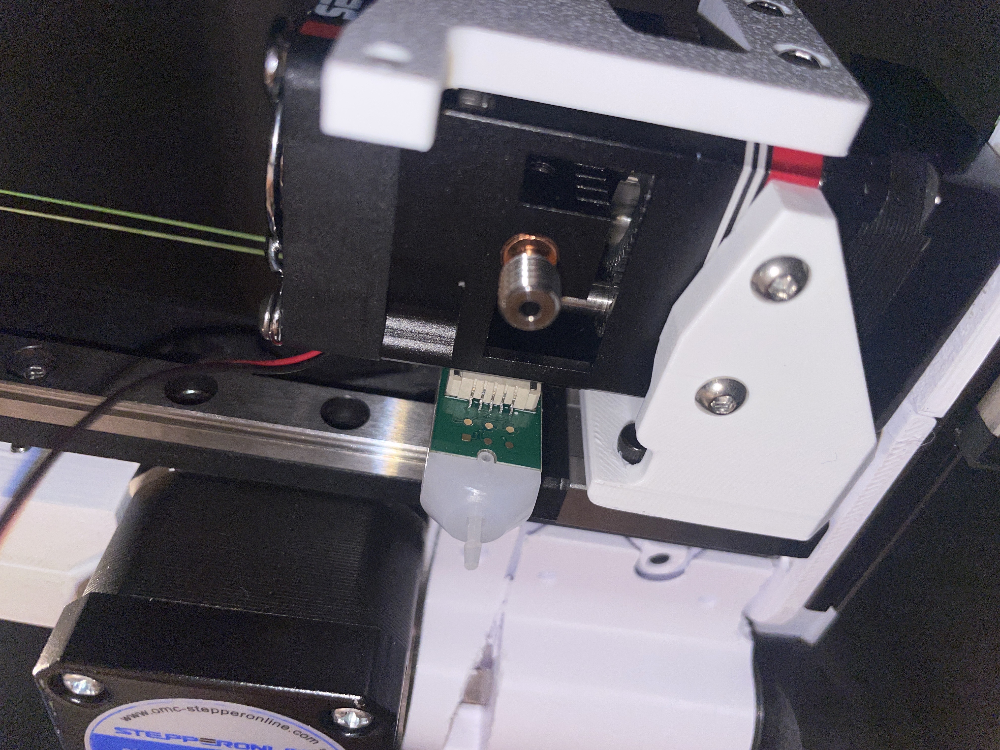
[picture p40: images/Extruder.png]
Extruder Area with BLTouch

*Extruder Area with BLTouch*

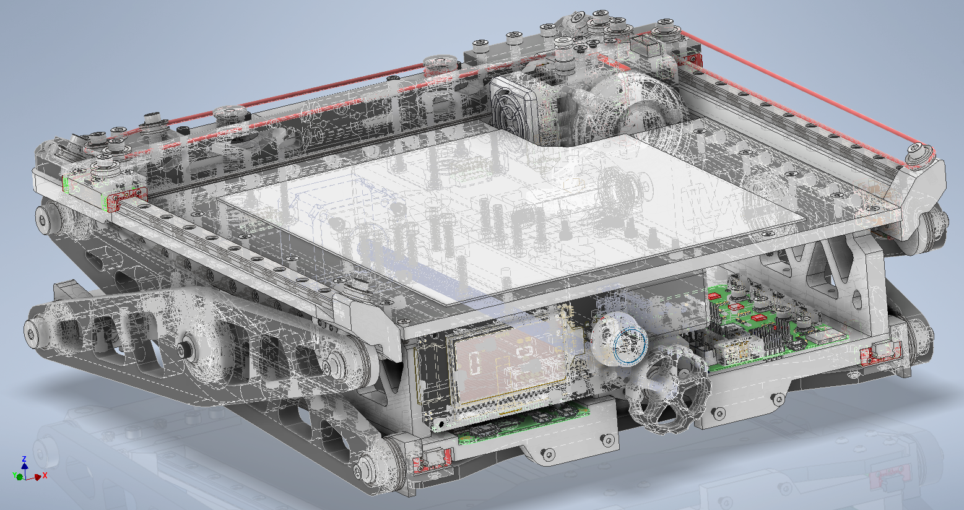
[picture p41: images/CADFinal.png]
Completed V1 CAD

*Completed V1 CAD*

stowed
*stowed*

### May 18 — The V2 fork

Decision, get v1 to first-print state in 1-2 weeks for closure, then pivot to v2 CAD. v1 lessons feed forward, iteration stories beat clean pivots.

Dual side lead screws confirmed as the central v2 architecture change, replacing the single central screw:

- The central screw dictated the entire superstructure. The bottom bridge plate had to tie both sides together, which forced the surrounding frames. Removing it collapses the dependency chain and opens a central cavity big enough for a full spool. Shortening the rear pivot bolts opens further space.
- Eliminates single-point gantry racking (Voron 2.4 / RatRig precedent).
- Independent motors over a belt-synced pair, Klipper Z_TILT_ADJUST is too valuable to give up, especially on a machine that gets folded and redeployed where the frame may not unfold to exact tolerance every time.
- Screws placed along the scissor pivot axis so they fold into the same plane as the scissors. Screw length cannot exceed folded height, which couples build height to folded thickness.
- Lead screws with anti-backlash nuts over ball screws (cheaper, quieter, alignment-abuse tolerant), T8x8 standard.
- Electronics relocate behind the filament roll. Filament path must not cross the PCB, board must stay accessible without removing the spool.

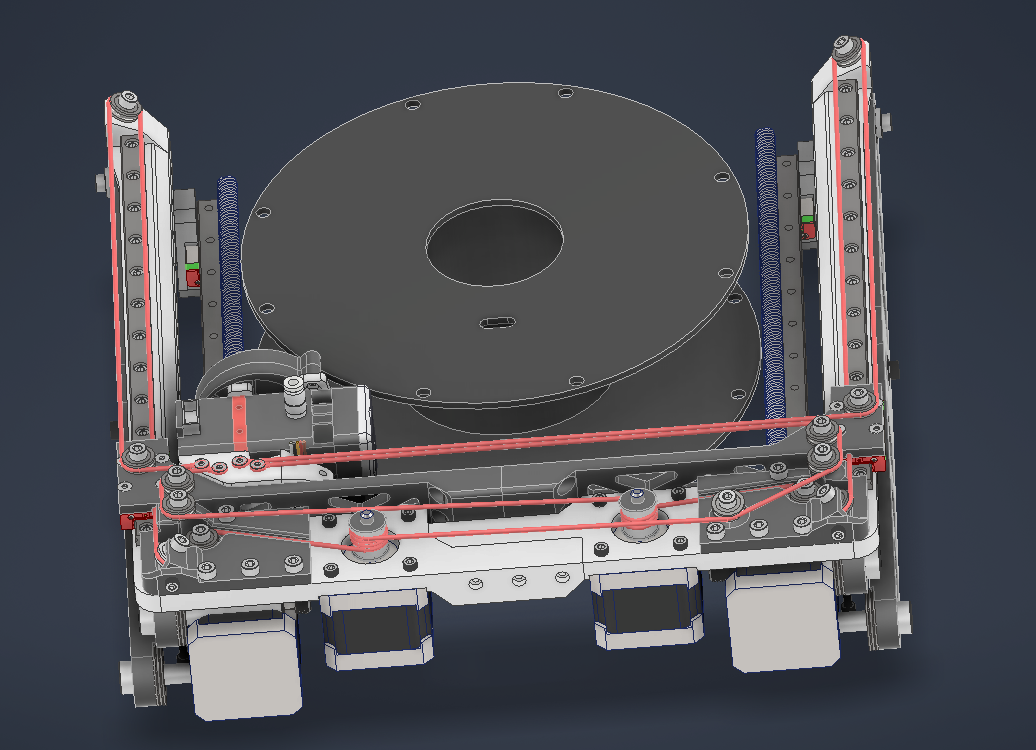
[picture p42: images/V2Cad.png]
V2 aims to store an entire filament roll inside

*V2 drops the battery and aims to store an entire filament roll inside*

The 90° toolhead problem named explicitly. An H2 cannot be rotated, its motor and gear geometry assume vertical filament drop. Paths considered, commission the open-source Positron 90° hotend + horizontal extruder (fastest, proven), design a custom horizontal extruder around the Positron hotend (~4 weeks CAD + machining), or full scratch design (3-6 months, kills the timeline).

Mod-a-Positron vs ground-up analysis. Modding fails on three fronts, no internal volume exists for a 500g spool bay (forces a frame redesign, not a mod), PSU sizing (~360W needed with a 150W bed + 100W chamber heater vs a ~150-200W stock bay), and electronics must relocate outside the heated zone (NEMA 17s lose torque above ~80°C ambient, drivers definitely move). Alternatives, build a stock Positron as a test mule to validate the thermal model, or fork the CC-BY-SA CAD and spend the design budget on the differentiators. Estimate 3-5 months from a fork vs 5-7 ground-up.

Proton analysis (the larger machine from the Positron team). It validated the battery de-prioritization, Proton uses USB-C PD as failover only with mains primary and kills one of two bed zones in battery mode. The same conclusion reached independently here, battery is a transport feature between mains locations, not a primary mode. Three differentiators confirmed unclaimed, integrated folding enclosure (Proton punts, suggesting a collapsible painting tent), internal filament storage (their Gluon extruder is about extruder compactness, not spool storage), and tool battery support (USB-C PD caps at 100-140W and most PD banks don't deliver it). Proton's strain-gauge nozzle-tap leveling is now table stakes and was added to the v2 spec.

The v2 repositioning, stated plainly. v1's logic was battery + low power, therefore no heated bed. v2 inverts it. Drop the onboard battery entirely (a liability, and true off-grid printing is rare in practice), add a heated bed and a folding bellows enclosure targeting a 50-60°C chamber for ABS/ASA/nylon, and take power from a front-mounted power tool battery (Milwaukee M18 / DeWalt) replacing the screen, 2-4 hour transport-mode printing (PLA only, no chamber heat), mains-powered charging in a future version. No longer an off-grid machine, a foldable enclosed transportable printer that runs on job-site batteries and prints engineering plastics.

Remaining v2 work as listed, dual side lead screws with software Z-tilt, folding bellows enclosure (50-60°C), heated bed sized for chamber and power budget, tool battery mounting blocks, custom 90° hotend with rear cable routing (kills the floppy top conduit), 3mm GT2 belt drive, HBot first with CoreXY fallback if racking forces are too high.

Open TBDs flagged, build volume target (drives enclosure, bed, spool clearance, PSU), 500g vs 1kg spool, folded dimension target, bed surface (settled toward PEI flex steel, dual heating zones, under-bed insulation), custom integrated board vs Pi + SKR.

Summer timeline, weeks 1-2 v1 first print + closure video, weeks 3-6 v2 CAD + commission toolhead, weeks 7-10 build and iterate, weeks 11-13 launch content + waitlist, kit fulfillment spring 2027.

### May 23 — Viability check

Demand validation friction ladder, email waitlist, paid IP sales, refundable deposits, small accessory sales. Revenue bracketed honestly, $25-50k bear to $300-700k+ bull depending on quality, distribution, and reseller partnerships. Questioned the effort-to-revenue ratio against simpler consumer products, the structural answer is TAM, purchase frequency, and decision friction differ, and the project's real value is career capital and optionality. Disposed of several kilograms of failed PLA parts from the v1 build.

---

## June 2026

### June 2 — Bellows physics, leveling validity

- For a 40-60°C FDM chamber the dominant heat loss is convective/air leakage, not radiation. Bellows material spec therefore, air-impermeable, heat-tolerant to ~60°C, fold-capable without cracking. Primary candidates, TPU film (transparent) or TPU-coated polyester fabric (opaque). Silicone-coated fiberglass considered earlier.
- Three-point leveling validity, two corners plus one midpoint is fully valid. Equilateral is the theoretical optimum but the performance curve is very flat. The real failure modes are skinny/near-collinear triangles and mounts that don't coincide with actual structural support points.
- Confirmed for travel, the printer (no battery), bench PSU, wires, and boards are all permitted carry-on across US/Canada/international security.

### June 8 — Scissor layout final analysis, repo

Four bed-support configurations ranked with stiffness as the sole criterion:

1. Four-edge scissors, synchronized. Stiffest, but statically indeterminate. A rigid plate has exactly three out-of-plane DOF (heave, pitch, roll), a fourth support is redundant. Load distribution then depends on relative support heights, and with lead screw lash, joint tolerance, and thermal growth the four supports will not match, so the bed either rocks (four-legged-table wobble) or gets bent as supports fight. Four driven points over-define the leveling plane, Z_TILT_ADJUST assumes an exactly-constrained set. On a machine that folds and redeploys, every redeployment resettles the four supports differently. Justified only at bed sizes where three-point sag is real.
2. Three-point (two scissors + passive diagonal, or three scissors). Fully constrains all out-of-plane DOF with zero redundancy, exact-constraint leveling, no fighting. The winner for a small portable bed. Caveat, a passive support must be low-friction in Z (linear bearing or rail, not a sliding fit) or it binds against the lead screw leveling.
3. Opposite-side two. One directly supported tilt axis, one soft joint-compliance-limited axis.
4. Adjacent-L unsupported. Worst, full-diagonal cantilever sag.

Side conclusion, if bed flatness under load is the worry, stiffen the plate (thickness, ribbing, material) rather than add a fourth lift. It helps every layout without importing over-constraint.

Repo published at github.com/ethangao907/Portable3DPrinter. Firmware/software under GPLv3, hardware design files under CERN-OHL-S v2 (added manually as LICENSE-hardware). Design files live in the `Scissor 3D Printer` folder.

Current v2 hardware as of this entry, "Foldup 3D printer" assembly in Onshape (668 instances), dual lead-screw Z, Dragon Burner V8 toolhead, Sherpa Micro extruder, SKR Mini controller, heated bellows enclosure for engineering plastics.

---

## V1 final configuration (as built)

- Scissor-lift Z, central lead screw, Klipper nonlinear Z mapping
- Dyneema CoreXY, rear screw tensioners
- BTT SKR Mini E3 V3 + Raspberry Pi 4, 24V bus
- Folds to ~300×300×80mm, ~180×200×175mm build volume
- No enclosure, no heated bed
- Deploys, homes, and prints

## V2 direction (active)

- Dual independent side lead screws, Z_TILT_ADJUST, central filament bay (500g internal, 1kg external optional)
- Folding bellows enclosure, 50-60°C chamber, ~80W chamber heater
- Heated bed, PEI flex steel, dual zones, under-bed insulation
- Tool battery mounting blocks front, onboard battery deleted
- Custom 90° hotend, rear cable routing
- 3mm GT2 belt, HBot first, CoreXY fallback
- Strain-gauge nozzle-tap leveling
- Three-point bed support

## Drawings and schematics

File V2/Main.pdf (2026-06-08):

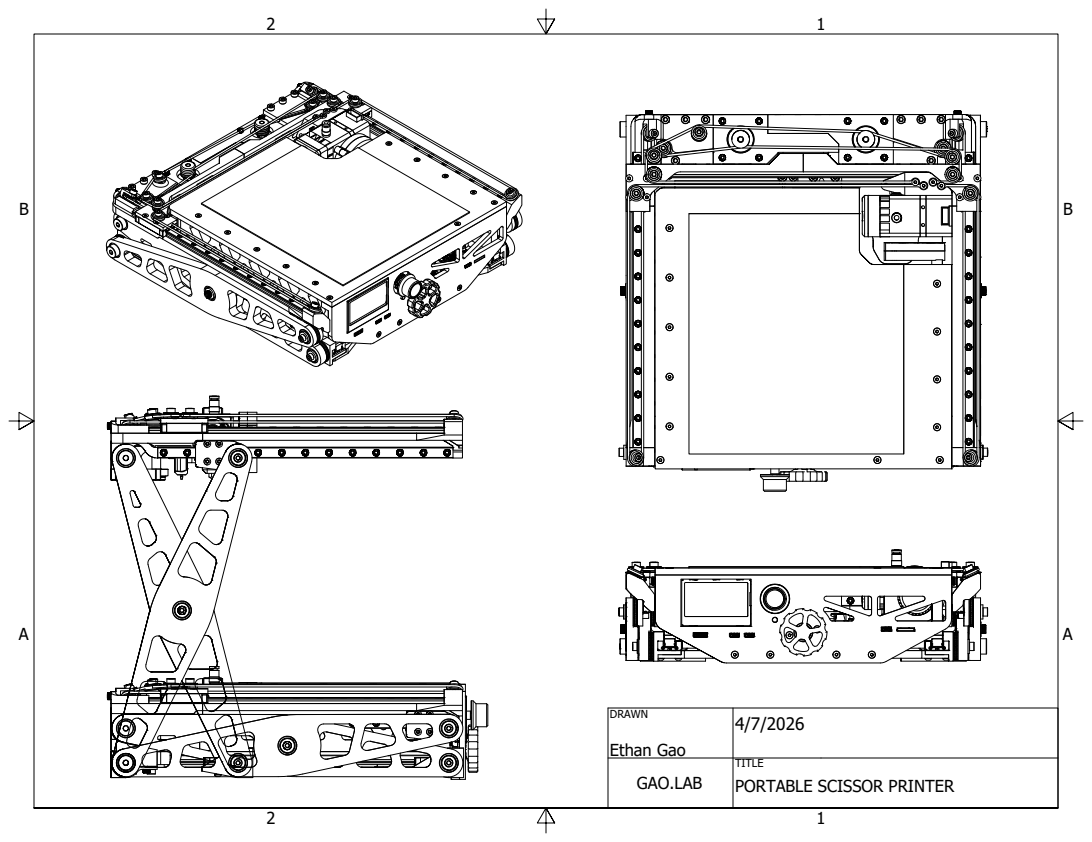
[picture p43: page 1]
Ethan Gao; GAO.LAB; PORTABLE SCISSOR PRINTER
